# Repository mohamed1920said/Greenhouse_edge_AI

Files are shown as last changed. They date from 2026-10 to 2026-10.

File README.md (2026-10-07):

# Edge-AI Smart Greenhouse

This repository is an experimental greenhouse monitoring and control project built around an ESP32-class controller. It combines environmental sensors, relay-driven actuators, MQTT/Node-RED connectivity, over-the-air updates, persistent setpoints, and an Edge Impulse anomaly model. It also contains the project's firmware history and KiCad hardware designs.

The project is a prototype, not a finished safety controller. The firmware and PCB directories contain several generations with different assumptions. Start with `code section/final/final.ino` for the most integrated implementation, then verify it against the exact PCB and board you intend to use before compiling or wiring anything.

## System overview

```text
DHT22 + BH1750 + soil + flow + AC-voltage + DS1302
                         |
                         v
                    ESP32 tasks
              sensors / control / AI / MQTT
                 |                     |
                 v                     v
      heater, fan, pump,          MQTT broker
      humidifier, light           and Node-RED
```

The current `final.ino` uses FreeRTOS tasks to:

- sample temperature, humidity, light, soil moisture, water flow, AC voltage, and RTC time every two seconds;
- operate heater, fan, irrigation pump, humidifier, and grow light in automatic or manual mode;
- run an Edge Impulse anomaly classifier every five seconds and add rule-based fault diagnoses;
- publish state as JSON and accept JSON commands through MQTT every two seconds; and
- service Arduino OTA updates from the main loop.

Setpoints are stored in ESP32 Preferences/NVS and survive a restart.

## Repository map

| Path | Contents |
| --- | --- |
| `code section/final/final.ino` | Integrated firmware and the recommended starting point for review. |
| `code section/V0` through `V6`, and `V8` through `V11` | Historical firmware iterations. `V7` is not present; these are alternatives, not modules to compile together. |
| `code section/TEST PCB/CODE/CODE.ino` | PCB-oriented test firmware. |
| `code section/logger/` | Python serial logger and an example CSV log. |
| `code section/LIBRARY/GreenhouseDashboard .zip` | Archived dashboard-related project files. |
| `ia library/ei-mohamed_said-project-1-arduino-1.0.11.zip` | Exported Edge Impulse Arduino inference library used by `final.ino`. |
| `LIBRARY/` | Archived SimpleTimer and DHT library packages used during earlier iterations. |
| `NODE RED/flows.json` | Node-RED flow export. Review broker and topic settings before importing. |
| `PCB/central/` | KiCad central-board design and backups. |
| `PCB/central/external/` | KiCad external-board design, a nested `pfe` design, and backups. |
| `iot-dashboard`, `PCB/central/.history`, `PCB/central/external/.history` | Gitlink entries whose referenced repositories are not configured in this repository. |

Do not assume that a pin map or sensor type from an older `V*` directory matches `final.ino`; variants in this repository use different hardware and dependencies.

The three Gitlink entries above are stored like submodules, but there is no `.gitmodules` file with their source URLs. A normal clone therefore cannot retrieve their contents with `git submodule update`; the original repository locations would need to be identified and configured first.

## Current firmware pin map

The following table describes only `code section/final/final.ino`:

| Function | GPIO | Notes |
| --- | ---: | --- |
| BH1750 SDA / SCL | 8 / 9 | I2C address `0x23`. |
| DHT22 data | 4 | `DHTTYPE` is `DHT22`. |
| Soil-moisture analog input | 14 | Mapped from raw dry `3200` and wet `1100` to 0-100%; recalibrate for the actual probe. |
| Water-flow pulse input | 10 | Interrupt input with pull-up; conversion assumes 7.5 pulses per flow-rate unit. |
| Heater relay | 5 | Active low in the helper functions. |
| Fan relay | 6 | Active low. |
| Irrigation-pump relay | 7 | Active low. |
| Humidifier output | 15 | Active high, unlike the other actuator relays. |
| Light relay | 16 | Active low. |
| Red alarm LED | 42 | Driven high during configured lockout conditions. |
| AC-voltage analog input | 3 | Uses a firmware calibration factor of `237.0`; requires a safe isolated sensing circuit. |
| DS1302 CLK / DAT / RST | 11 / 12 / 13 | Three-wire RTC connection. |

These GPIO numbers are board-specific. Select an ESP32 variant that exposes them, check boot/strapping and ADC restrictions, and compare this table with the selected KiCad revision before connecting hardware.

## Firmware dependencies

Use an Arduino-compatible ESP32 development environment and install the libraries required by `final.ino`:

- DHT sensor library;
- BH1750;
- PubSubClient;
- ArduinoJson;
- a DS1302-compatible RTC library providing `ThreeWire.h` and `RtcDS1302.h`;
- the Edge Impulse Arduino library from `ia library/ei-mohamed_said-project-1-arduino-1.0.11.zip`; and
- the Wi-Fi, Preferences, ArduinoOTA, Wire, and FreeRTOS support supplied by the chosen ESP32 Arduino core.

Library and ESP32-core versions are not pinned. Record known-good versions after the first successful build.

## Configuration and first run

1. Review the schematic and choose the firmware/PCB revision that matches the assembled hardware.
2. Install the dependencies and import the Edge Impulse ZIP as an Arduino library.
3. In `final.ino`, replace `WIFI_SSID`, `WIFI_PASS`, `MQTT_SERVER`, and `MQTT_PORT` with values for the deployment network. Do not publish real credentials in source control.
4. Verify every GPIO, relay active level, soil calibration point, flow-sensor factor, and voltage-sensor calibration with actuators disconnected.
5. Start an MQTT broker reachable from the controller. The checked-in defaults point to `192.168.4.1:1883` without authentication or TLS.
6. Optionally import `NODE RED/flows.json`, then inspect all nodes and broker settings before deploying the flow. The exported flow targets HiveMQ Cloud over TLS on port 8883, while `final.ino` targets `192.168.4.1:1883` without TLS or authentication; the two configurations will not interoperate unchanged.
7. Build and upload `code section/final/final.ino`, open a serial monitor at `115200`, and validate sensor readings.
8. Test one low-voltage actuator channel at a time. Only connect pumps, heaters, or mains-powered equipment after the logic and fail-safe states have been independently verified.

`connectWiFi()` blocks until the configured network becomes available. A wrong SSID/password therefore prevents the remaining setup from completing.

## MQTT interface

The device uses these topics:

| Direction | Topic | Purpose |
| --- | --- | --- |
| Device to broker | `greenhouse/data` | Sensor values, actuator state, anomaly result, mode, setpoints, and manual commands. |
| Broker to device | `greenhouse/commands` | Mode, setpoint, and actuator-command changes. |

Example automatic-mode configuration:

```json
{
  "mode": "AUTO",
  "temp_low": 18,
  "temp_high": 26,
  "hum_low": 50,
  "lux_low": 50,
  "moist_low": 30
}
```

Example manual command:

```json
{
  "mode": "MANUAL",
  "heater": false,
  "fan": true,
  "pump": false,
  "humid": false,
  "light": true
}
```

Telemetry includes `temp`, `humid`, `lux`, `moist`, `water_flow`, `mains_voltage`, the five `*_state` fields, `anomaly_score`, `diagnosis`, `mode`, `hour`, the current setpoints, and the five `cmd_*` fields. Invalid DHT readings are published as JSON `null`.

## Automatic control and diagnostics

The checked-in defaults are 18-26 deg C, 50% minimum humidity, 50 lux minimum light, and 30% minimum soil moisture. In automatic mode:

- the heater runs below the low-temperature setpoint and the fan above the high-temperature setpoint;
- the humidifier runs below the humidity setpoint;
- the pump runs below the soil-moisture setpoint; and
- the light uses a 150-lux off hysteresis above its on threshold.

The AI input repeats temperature, humidity, soil moisture, light, and water-flow values across the model frame. Rule-based diagnoses take priority for invalid DHT data, pump-without-flow, flow-without-pump, low temperature while heating, and low humidity while humidifying. An anomaly score above `3.0` otherwise produces a warning.

The controller switches off selected loads and lights the red LED when measured AC voltage is between 10 V and 190 V, or when the diagnosis contains `CRITICAL`. This logic is an application safeguard, not certified electrical protection.

## Known limitations

- Wi-Fi credentials and broker details are hard-coded. MQTT has no authentication or TLS, and OTA has no configured password.
- The code reads the RTC hour but currently sets `isDaytime = true`; automatic lighting is therefore not actually limited to the stated day period.
- The AC-voltage calculation assumes a particular 240 V sensor calibration. It must not be connected directly to mains, and its values are not reliable on different hardware without calibration.
- Brownout lockout is applied only when the measured voltage is above 10 V and below 190 V. A disconnected or failed sensing circuit that reports 0 V bypasses this check rather than forcing a safe state.
- On a DHT failure, automatic temperature/humidity branches skip new commands, so prior fan or humidifier states can remain latched. The resulting `CRITICAL` path explicitly switches off only the heater and pump; it does not force every actuator off.
- Soil and flow conversions use fixed calibration constants. Edge Impulse results are meaningful only if sensor order, units, preprocessing, and library export match the model's training data.
- Relay polarity is mixed: the humidifier is active high while the other actuator helpers are active low.
- Historical firmware, archived libraries, Node-RED flow, and PCB backups can conflict with the final sketch. There is no single checked-in bill of materials or version manifest tying them together.
- Three Gitlink entries have no matching `.gitmodules` configuration, so the dashboard and history content they reference is not reproducible from this repository alone.
- Control and network loops have not been demonstrated here as fault tolerant. Network loss, MCU reset, stuck relays, sensor disconnection, dry running, and watchdog behavior require explicit tests.

## Safety

Heaters, pumps, humidifiers, grow lights, relays, water, and mains sensing create fire, shock, flooding, and equipment hazards. Use isolated and correctly rated power supplies, relay/driver modules, fuses, grounding, enclosures, strain relief, emergency shutoff, and independent temperature/water-level protection. Keep low-voltage electronics separated from mains and wet areas. Test with safe dummy loads first, and do not operate this prototype unattended or use it as the only protection for plants, property, or people.

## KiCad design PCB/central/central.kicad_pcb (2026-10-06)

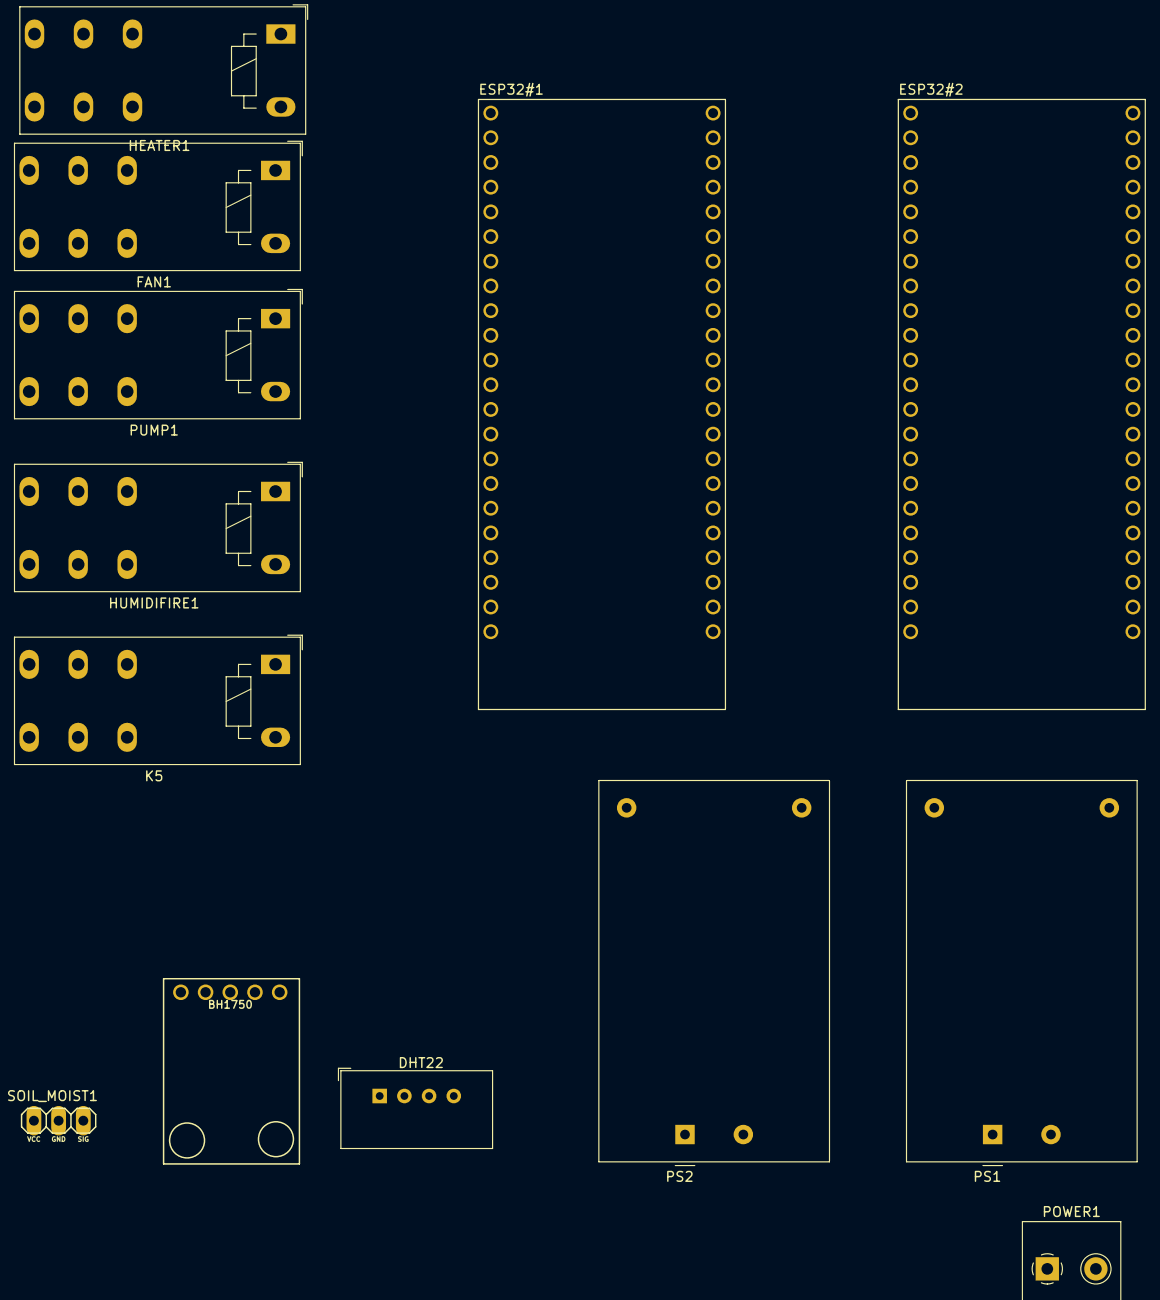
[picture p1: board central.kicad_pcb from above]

Board: 2 copper layers, 13 parts (0 on the bottom side), 14 nets, no tracks yet.

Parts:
BH1750: ZC362800_
DHT22: AM2302; ASAIR_AM2302_P2.54mm_Vertical
ESP32#1, ESP32#2: ESP32-S3-DEVKITC-1U-N8R8; MODULE_ESP32-S3-DEVKITC-1U-N8R8
FAN1: RT314A05; Relay_SPDT_Schrack-RT1-16A-FormC_RM5mm
HEATER1: RT314A05; Relay_SPDT_Schrack-RT1-16A-FormC_RM5mm
HUMIDIFIRE1: RT314A05; Relay_SPDT_Schrack-RT1-16A-FormC_RM5mm
K5: GROW_LIGHT; Relay_SPDT_Schrack-RT1-16A-FormC_RM5mm
POWER1: Screw_Terminal_01x02; TerminalBlock_Philmore_TB132_1x02_P5.00mm_Horizontal
PS1: HLK-5M05; Converter_ACDC_HiLink_HLK-5Mxx
PS2: HLK-5M12; Converter_ACDC_HiLink_HLK-5Mxx
PUMP1: RT314A05; Relay_SPDT_Schrack-RT1-16A-FormC_RM5mm
SOIL_MOIST1: SEN-13322

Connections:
3V3: ESP32#1.J1_1 (3V3), ESP32#1.J1_2 (3V3), ESP32#2.J1_1 (3V3), ESP32#2.J1_2 (3V3)
5V: BH1750.VCC, DHT22.1 (VDD), ESP32#2.J1_21 (5V0), HUMIDIFIRE1.11, K5.11, PS1.4 (+Vout), SOIL_MOIST1.1 (VCC)
12V: FAN1.11, HEATER1.11, PS2.4 (+Vout), PUMP1.11
GND: BH1750.GND, DHT22.3 (GND), DHT22.4 (GND), ESP32#1.J1_22 (GND), ESP32#1.J3_1 (GND), ESP32#1.J3_21 (GND), ESP32#1.J3_22 (GND), ESP32#2.J1_22 (GND), ESP32#2.J3_1 (GND), ESP32#2.J3_21 (GND), ESP32#2.J3_22 (GND), FAN1.A1, HEATER1.A1, HUMIDIFIRE1.A1, K5.A1, PS1.3 (-Vout), PS2.3 (-Vout), PUMP1.A1, SOIL_MOIST1.2 (GND)
unnamed: POWER1.1, PS1.1 (AC/L), PS2.1 (AC/L)
unnamed: POWER1.2, PS1.2 (AC/N), PS2.2 (AC/N)
PIN_5: ESP32#1.J1_5 (GPIO5), HEATER1.A2
PIN_6: ESP32#1.J1_6 (GPIO6), FAN1.A2
PIN_7: ESP32#1.J1_7 (GPIO7), PUMP1.A2
PIN_8: BH1750.SDA, ESP32#1.J1_12 (GPIO8)
PIN_9: BH1750.SCL, ESP32#1.J1_15 (GPIO9)
PIN_14: ESP32#1.J1_20 (GPIO14), SOIL_MOIST1.3 (SIG)
PIN_15: ESP32#1.J1_8 (GPIO15), HUMIDIFIRE1.A2
PIN_16: ESP32#1.J1_9 (GPIO16), K5.A2

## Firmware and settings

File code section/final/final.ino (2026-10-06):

#include <DHT.h>
#include <Wire.h>
#include <BH1750.h>
#include <WiFi.h>
#include <WiFiClient.h>
#include <PubSubClient.h>
#include <ArduinoJson.h>
#include <Preferences.h>
#include <ArduinoOTA.h>

// --- NEW RTC LIBRARIES (DS1302) ---
#include <ThreeWire.h>  
#include <RtcDS1302.h>


#include <mohamed_said-project-1_inferencing.h>

// =============================================================
// WIFI + MQTT (LOCAL BROKER)
// =============================================================
const char* WIFI_SSID   = "GreenhouseNet";
const char* WIFI_PASS   = "12345678";
const char* MQTT_SERVER = "192.168.4.1";
const int   MQTT_PORT   = 1883;

const char* TOPIC_DATA  = "greenhouse/data";
const char* TOPIC_CMD   = "greenhouse/commands";

// =============================================================
// PINS
// =============================================================
#define PIN_SDA      8   // I2C for BH1750
#define PIN_SCL      9   // I2C for BH1750
#define PIN_DHT      4
#define PIN_SOIL     14
#define PIN_WATER    10
#define PIN_HEATER   5
#define PIN_FAN      6
#define PIN_PUMP     7
#define PIN_HUMID    15
#define PIN_LIGHT    16
#define PIN_LED_RED  42
#define PIN_VOLTAGE  3   

// DS1302 RTC Pins
#define PIN_RTC_CLK  11
#define PIN_RTC_DAT  12
#define PIN_RTC_RST  13

// =============================================================
// DRIVERS & GLOBALS
// =============================================================
#define DHTTYPE DHT22
DHT dht(PIN_DHT, DHTTYPE);
BH1750 lightMeter;
WiFiClient espClient;
PubSubClient client(espClient);
Preferences preferences;

// Initialize DS1302
ThreeWire myWire(PIN_RTC_DAT, PIN_RTC_CLK, PIN_RTC_RST); // DAT, CLK, RST
RtcDS1302<ThreeWire> rtc(myWire);

// =============================================================
// SETTINGS
// =============================================================
const float ANOMALY_THRESHOLD = 3.0f; 

volatile bool manualMode = false;

// Setpoints (Overwritten by Flash Memory)
float sp_temp_low  = 18.0f;
float sp_temp_high = 26.0f;
float sp_hum_low   = 50.0f;
float sp_lux_low   = 50.0f;
float sp_moist_low = 30.0f;

volatile int cmd_heater = 0;
volatile int cmd_fan    = 0;
volatile int cmd_pump   = 0;
volatile int cmd_humid  = 0;
volatile int cmd_light  = 0;

// =============================================================
// SHARED STATE
// =============================================================
struct SharedData {
  float temp, humid, lux, moist, water_flow, mains_voltage;
  int heater_state, fan_state, pump_state, light_state, humid_state;
  float anomaly_score;
  String diagnosis;
  int current_hour;
};

SharedData systemState = {
  0.0f, 0.0f, 0.0f, 0.0f, 0.0f, 0.0f,
  0, 0, 0, 0, 0,
  0.0f, "Booting...", 12
};

SemaphoreHandle_t xMutex = NULL;
float features[EI_CLASSIFIER_DSP_INPUT_FRAME_SIZE];

// =============================================================
// HELPERS
// =============================================================
void relayWrite(int pin, bool turnOn) {
  if (pin == PIN_HUMID) digitalWrite(pin, turnOn ? HIGH : LOW);
  else digitalWrite(pin, turnOn ? LOW : HIGH);
}

int relayRead(int pin) {
  if (pin == PIN_HUMID) return (digitalRead(pin) == HIGH) ? 1 : 0;
  else return (digitalRead(pin) == LOW) ? 1 : 0;
}

float readSoilMoisture() {
  const int raw_dry = 3200, raw_wet = 1100;
  int raw = analogRead(PIN_SOIL);
  float pct = (float)(raw_dry - raw) / (float)(raw_dry - raw_wet) * 100.0f;
  if (pct < 0.0f) pct = 0.0f;
  if (pct > 100.0f) pct = 100.0f;
  return pct;
}

volatile uint32_t flowPulseCount = 0;
void IRAM_ATTR flowPulseISR() { flowPulseCount++; }
float calculateFlowRate(uint32_t elapsedMs) {
  uint32_t pulses = flowPulseCount; flowPulseCount = 0;
  if (elapsedMs == 0) return 0.0f;
  return ((pulses * 1000.0f) / elapsedMs) / 7.5f; 
}

float readACVoltage() {
  uint32_t start_time = millis();
  int max_val = 0, min_val = 4095;
  while((millis() - start_time) < 40) { // 40ms = 2 full AC cycles
    int val = analogRead(PIN_VOLTAGE);
    if(val > max_val) max_val = val;
    if(val < min_val) min_val = val;
  }
  float v_pp = ((max_val - min_val) * 3.3f) / 4095.0f;
  float v_rms = v_pp / 2.828f;
  float CALIBRATION_FACTOR = 237.0f; // Calibrated for 240V
  float actual_voltage = v_rms * CALIBRATION_FACTOR;
  if (actual_voltage < 10.0f) actual_voltage = 0.0f; 
  return actual_voltage;
}

// =============================================================
// MQTT & WIFI
// =============================================================
void connectWiFi() {
  WiFi.mode(WIFI_STA); WiFi.begin(WIFI_SSID, WIFI_PASS);
  while (WiFi.status() != WL_CONNECTED) delay(500);
}

void reconnectMQTT() {
  if (WiFi.status() == WL_CONNECTED && client.connect("ESP32_GH")) {
    client.subscribe(TOPIC_CMD);
  }
}

void onMqttMessage(char* topic, byte* payload, unsigned int length) {
  StaticJsonDocument<512> doc;
  if (deserializeJson(doc, payload, length)) return;

  if (xSemaphoreTake(xMutex, pdMS_TO_TICKS(100)) == pdTRUE) {
    if (doc.containsKey("mode")) manualMode = (doc["mode"].as<String>() == "MANUAL");

    bool configChanged = false;
    if (doc.containsKey("temp_low"))  { sp_temp_low  = doc["temp_low"]; configChanged = true; }
    if (doc.containsKey("temp_high")) { sp_temp_high = doc["temp_high"]; configChanged = true; }
    if (doc.containsKey("hum_low"))   { sp_hum_low   = doc["hum_low"]; configChanged = true; }
    if (doc.containsKey("lux_low"))   { sp_lux_low   = doc["lux_low"]; configChanged = true; }
    if (doc.containsKey("moist_low")) { sp_moist_low = doc["moist_low"]; configChanged = true; }
    if (sp_temp_high < sp_temp_low) { float t = sp_temp_low; sp_temp_low = sp_temp_high; sp_temp_high = t; }

    if (configChanged) {
      preferences.putFloat("sp_t_l", sp_temp_low); preferences.putFloat("sp_t_h", sp_temp_high);
      preferences.putFloat("sp_h_l", sp_hum_low); preferences.putFloat("sp_l_l", sp_lux_low);
      preferences.putFloat("sp_m_l", sp_moist_low);
    }

    if (doc.containsKey("heater")) cmd_heater = doc["heater"] ? 1 : 0;
    if (doc.containsKey("fan"))    cmd_fan    = doc["fan"] ? 1 : 0;
    if (doc.containsKey("pump"))   cmd_pump   = doc["pump"] ? 1 : 0;
    if (doc.containsKey("humid"))  cmd_humid  = doc["humid"] ? 1 : 0;
    if (doc.containsKey("light"))  cmd_light  = doc["light"] ? 1 : 0;

    xSemaphoreGive(xMutex);
  }
}

// =============================================================
// TASKS
// =============================================================
void TaskSensors(void* pvParameters) {
  uint32_t lastFlowCheck = millis();
  for (;;) {
    float t = dht.readTemperature(); float h = dht.readHumidity();
    float l = lightMeter.readLightLevel(); float m = readSoilMoisture();
    uint32_t now = millis(); float w = calculateFlowRate(now - lastFlowCheck); lastFlowCheck = now;
    float v_ac = readACVoltage();
    
    // Get Time from DS1302
    RtcDateTime now_time = rtc.GetDateTime();

    if (isnan(t) || t < -40 || t > 80) t = -999.0f;
    if (isnan(h) || h < 0 || h > 100) h = -999.0f;
    if (l < 0) l = 0;

    if (xSemaphoreTake(xMutex, portMAX_DELAY) == pdTRUE) {
      systemState.temp = t; systemState.humid = h; systemState.lux = l;
      systemState.moist = m; systemState.water_flow = w; systemState.mains_voltage = v_ac;
      systemState.heater_state = relayRead(PIN_HEATER); systemState.fan_state = relayRead(PIN_FAN);
      systemState.pump_state = relayRead(PIN_PUMP); systemState.light_state = relayRead(PIN_LIGHT);
      systemState.humid_state = relayRead(PIN_HUMID); systemState.current_hour = now_time.Hour(); 
      xSemaphoreGive(xMutex);
    }
    vTaskDelay(2000 / portTICK_PERIOD_MS);
  }
}

void TaskAI(void* pvParameters) {
  for (;;) {
    float t, h, l, m, w; int pump_state, heater_state, humid_state, light_state;
    if (xSemaphoreTake(xMutex, portMAX_DELAY) == pdTRUE) {
      t = systemState.temp; h = systemState.humid; l = systemState.lux; m = systemState.moist; w = systemState.water_flow;
      pump_state = systemState.pump_state; heater_state = systemState.heater_state; 
      humid_state = systemState.humid_state; light_state = systemState.light_state;
      xSemaphoreGive(xMutex);
    }

    for (size_t i = 0; i < EI_CLASSIFIER_DSP_INPUT_FRAME_SIZE; i += 5) {
      features[i] = t; if (i+1 < EI_CLASSIFIER_DSP_INPUT_FRAME_SIZE) features[i+1] = h;
      if (i+2 < EI_CLASSIFIER_DSP_INPUT_FRAME_SIZE) features[i+2] = m;
      if (i+3 < EI_CLASSIFIER_DSP_INPUT_FRAME_SIZE) features[i+3] = l;
      if (i+4 < EI_CLASSIFIER_DSP_INPUT_FRAME_SIZE) features[i+4] = w;
    }

    signal_t signal; numpy::signal_from_buffer(features, EI_CLASSIFIER_DSP_INPUT_FRAME_SIZE, &signal);
    ei_impulse_result_t result = { 0 }; run_classifier(&signal, &result, false);

    float score = result.anomaly; String diag = "Normal";

    if (t == -999.0f) diag = "CRITICAL: Temperature sensor failure";
    else if (h == -999.0f) diag = "CRITICAL: Humidity sensor failure";
    else if (pump_state == 1 && w < 0.1f) diag = "CRITICAL: Pipe blocked (pump ON, no flow)";
    else if (pump_state == 0 && w > 0.1f) diag = "CRITICAL: Water leak detected";
    else if (heater_state == 1 && t < 15.0f) diag = "CRITICAL: Heater failure";
    else if (humid_state == 1 && h < 40.0f) diag = "CRITICAL: Humidifier failure";
    else if (score > ANOMALY_THRESHOLD) diag = "WARNING: AI detected abnormal environment";

    if (xSemaphoreTake(xMutex, portMAX_DELAY) == pdTRUE) {
      systemState.anomaly_score = score; systemState.diagnosis = diag;
      xSemaphoreGive(xMutex);
    }
    vTaskDelay(5000 / portTICK_PERIOD_MS);
  }
}

void TaskControl(void* pvParameters) {
  for (;;) {
    float t, h, l, m, v_ac; String diag; bool modeManual; int hr;
    float tLow, tHigh, hLow, luxLow, moistLow; int cHeater, cFan, cPump, cHumid, cLight;

    if (xSemaphoreTake(xMutex, portMAX_DELAY) == pdTRUE) {
      t = systemState.temp; h = systemState.humid; l = systemState.lux; m = systemState.moist; 
      v_ac = systemState.mains_voltage; diag = systemState.diagnosis; hr = systemState.current_hour;
      modeManual = manualMode; tLow = sp_temp_low; tHigh = sp_temp_high; hLow = sp_hum_low; 
      luxLow = sp_lux_low; moistLow = sp_moist_low;
      cHeater = cmd_heater; cFan = cmd_fan; cPump = cmd_pump; cHumid = cmd_humid; cLight = cmd_light;
      xSemaphoreGive(xMutex);
    }

    bool safety_lockout = false;
    
    // BROWNOUT PROTECTION
    if (v_ac > 10.0f && v_ac < 190.0f) { 
      relayWrite(PIN_HEATER, false); relayWrite(PIN_PUMP, false); relayWrite(PIN_FAN, false);
      digitalWrite(PIN_LED_RED, HIGH); safety_lockout = true; 
    } 
    else if (diag.indexOf("CRITICAL") != -1) {
      relayWrite(PIN_HEATER, false); relayWrite(PIN_PUMP, false); 
      digitalWrite(PIN_LED_RED, HIGH); safety_lockout = true;
    } else {
      digitalWrite(PIN_LED_RED, LOW);
    }

    if (!safety_lockout) {
      if (modeManual) {
        relayWrite(PIN_HEATER, cHeater); relayWrite(PIN_FAN, cFan); relayWrite(PIN_PUMP, cPump);
        relayWrite(PIN_HUMID, cHumid); relayWrite(PIN_LIGHT, cLight);
      } else {
        
        // 1. THERMAL & MOISTURE
        if (t != -999.0f) {
          if (t < tLow) { relayWrite(PIN_HEATER, true); relayWrite(PIN_FAN, false); }
          else if (t > tHigh) { relayWrite(PIN_HEATER, false); relayWrite(PIN_FAN, true); }
          else { relayWrite(PIN_HEATER, false); relayWrite(PIN_FAN, false); }
        }
        if (h != -999.0f) relayWrite(PIN_HUMID, (h < hLow));
        relayWrite(PIN_PUMP,  (m < moistLow));
        
        bool isDaytime = true ; // 6 AM to 8 PM
        bool current_light = (relayRead(PIN_LIGHT) == 1);
        
        if (isDaytime) {
          if (!current_light && (l < luxLow)) {
            relayWrite(PIN_LIGHT, true);
          } 
          else if (current_light && (l > (luxLow + 150.0f))) {
            relayWrite(PIN_LIGHT, false);
          }
        } else {
          // It is Nighttime -> Force light OFF
          relayWrite(PIN_LIGHT, false);
        }
      }
    }
    vTaskDelay(2000 / portTICK_PERIOD_MS);
  }
}

void TaskMQTT(void* pvParameters) {
  for (;;) {
    if (WiFi.status() != WL_CONNECTED) connectWiFi();
    if (!client.connected()) reconnectMQTT();
    client.loop();

    StaticJsonDocument<768> doc;
    if (xSemaphoreTake(xMutex, portMAX_DELAY) == pdTRUE) {
      
      if (systemState.temp == -999.0f) doc["temp"] = nullptr;
      else doc["temp"] = systemState.temp;

      if (systemState.humid == -999.0f) doc["humid"] = nullptr;
      else doc["humid"] = systemState.humid;

      doc["lux"] = systemState.lux; doc["moist"] = systemState.moist; 
      doc["water_flow"] = systemState.water_flow; doc["mains_voltage"] = systemState.mains_voltage;
      
      doc["heater_state"] = relayRead(PIN_HEATER); doc["fan_state"] = relayRead(PIN_FAN);
      doc["pump_state"] = relayRead(PIN_PUMP); doc["light_state"] = relayRead(PIN_LIGHT);
      doc["humid_state"] = relayRead(PIN_HUMID);
      
      doc["anomaly_score"] = systemState.anomaly_score; doc["diagnosis"] = systemState.diagnosis;
      doc["mode"] = manualMode ? "MANUAL" : "AUTO";
      doc["hour"] = systemState.current_hour; 
      
      doc["temp_low"] = sp_temp_low; doc["temp_high"] = sp_temp_high; doc["hum_low"] = sp_hum_low;
      doc["lux_low"] = sp_lux_low; doc["moist_low"] = sp_moist_low;

      doc["cmd_heater"] = cmd_heater; doc["cmd_fan"] = cmd_fan; doc["cmd_pump"] = cmd_pump;
      doc["cmd_humid"] = cmd_humid; doc["cmd_light"] = cmd_light;
      xSemaphoreGive(xMutex);
    }

    char buffer[1024]; size_t n = serializeJson(doc, buffer, sizeof(buffer));
    if (n > 0) client.publish(TOPIC_DATA, buffer);
    vTaskDelay(2000 / portTICK_PERIOD_MS);
  }
}

// =============================================================
// SETUP & LOOP
// =============================================================
void setup() {
  Serial.begin(115200);
  preferences.begin("ghouse", false);
  sp_temp_low  = preferences.getFloat("sp_t_l", 18.0f);
  sp_temp_high = preferences.getFloat("sp_t_h", 26.0f);
  sp_hum_low   = preferences.getFloat("sp_h_l", 50.0f);
  sp_lux_low   = preferences.getFloat("sp_l_l", 50.0f);
  sp_moist_low = preferences.getFloat("sp_m_l", 30.0f);

  // Init Sensors
  Wire.begin(PIN_SDA, PIN_SCL);
  dht.begin();
  
  // Init DS1302
  rtc.Begin();
  RtcDateTime compiled = RtcDateTime(__DATE__, __TIME__);
  if (!rtc.IsDateTimeValid()) rtc.SetDateTime(compiled);
  if (!rtc.GetIsRunning()) rtc.SetIsRunning(true);
  
  Wire.beginTransmission(0x23);
  if (Wire.endTransmission() == 0) lightMeter.begin(BH1750::CONTINUOUS_HIGH_RES_MODE, 0x23, &Wire);

  // Init Pins
  pinMode(PIN_HEATER, OUTPUT); pinMode(PIN_FAN, OUTPUT); pinMode(PIN_PUMP, OUTPUT);
  pinMode(PIN_HUMID, OUTPUT); pinMode(PIN_LIGHT, OUTPUT); pinMode(PIN_LED_RED, OUTPUT);
  pinMode(PIN_WATER, INPUT_PULLUP);
  relayWrite(PIN_HEATER, false); relayWrite(PIN_FAN, false); relayWrite(PIN_PUMP, false);
  relayWrite(PIN_HUMID, false); relayWrite(PIN_LIGHT, false); digitalWrite(PIN_LED_RED, LOW);

  attachInterrupt(digitalPinToInterrupt(PIN_WATER), flowPulseISR, RISING);

  xMutex = xSemaphoreCreateMutex();
  connectWiFi();
  
  ArduinoOTA.setHostname("Smart-Greenhouse"); ArduinoOTA.begin();
  client.setServer(MQTT_SERVER, MQTT_PORT); client.setCallback(onMqttMessage);
  client.setBufferSize(1024); client.setKeepAlive(20); client.setSocketTimeout(3);

  // Start FreeRTOS Tasks
  xTaskCreatePinnedToCore(TaskSensors, "Sensors", 4096, NULL, 2, NULL, 1);
  xTaskCreatePinnedToCore(TaskControl, "Control", 6144, NULL, 1, NULL, 1);
  xTaskCreatePinnedToCore(TaskMQTT,    "MQTT",    6144, NULL, 1, NULL, 1);
  xTaskCreatePinnedToCore(TaskAI,      "AI",      8192, NULL, 1, NULL, 0);
}

void loop() {
  ArduinoOTA.handle();
  vTaskDelay(10 / portTICK_PERIOD_MS);
}

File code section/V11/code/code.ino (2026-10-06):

#include <DHT.h>
#include <Wire.h>
#include <BH1750.h>
#include <WiFi.h>
#include <WiFiClient.h>
#include <PubSubClient.h>
#include <ArduinoJson.h>
#include <SPI.h>
#include <SD.h>

// DS1302 (3-wire RTC: CLK/DATA/RST)
#include <ThreeWire.h>
#include <RtcDS1302.h>

#include <mohamed_said-project-1_inferencing.h>

// =============================================================
// WIFI + MQTT (LOCAL BROKER)
// =============================================================
const char* WIFI_SSID   = "GreenhouseNet";
const char* WIFI_PASS   = "12345678";
const char* MQTT_SERVER = "192.168.4.1";
const int   MQTT_PORT   = 1883;

const char* TOPIC_DATA  = "greenhouse/data";
const char* TOPIC_CMD   = "greenhouse/commands";

// =============================================================
// PINS (YOUR EXISTING PINS)
// =============================================================
#define PIN_SDA      8
#define PIN_SCL      9
#define PIN_DHT      4
#define PIN_SOIL     14
#define PIN_WATER    10
#define PIN_HEATER   5
#define PIN_FAN      6
#define PIN_PUMP     7
#define PIN_HUMID    16
#define PIN_LIGHT    15
#define PIN_LED_RED  42

// =============================================================
// ADD THESE PINS (YOU MUST SET THEM TO MATCH YOUR WIRING)
// =============================================================
// ---- RTC DS1302 pins (module: VCC GND CLK DATA RST) ----
#define PIN_RTC_CLK  1   // TODO: set to your RTC CLK GPIO
#define PIN_RTC_DAT  2   // TODO: set to your RTC DATA GPIO
#define PIN_RTC_RST  3   // TODO: set to your RTC RST/CE GPIO

// ---- SD card SPI pins (module: CS SCK MISO MOSI) ----
// IMPORTANT: do NOT conflict with PIN_WATER=10, and avoid your relay pins too.
#define PIN_SD_CS    41  // TODO: set to your SD CS GPIO
#define PIN_SD_SCK   40  // TODO: set to your SD SCK GPIO
#define PIN_SD_MISO  39  // TODO: set to your SD MISO GPIO
#define PIN_SD_MOSI  38  // TODO: set to your SD MOSI GPIO

// =============================================================
// DRIVERS
// =============================================================
#define DHTTYPE DHT11
DHT dht(PIN_DHT, DHTTYPE);
BH1750 lightMeter;
WiFiClient espClient;
PubSubClient client(espClient);

// RTC objects
ThreeWire rtcWire(PIN_RTC_DAT, PIN_RTC_CLK, PIN_RTC_RST); // DAT, CLK, RST
RtcDS1302<ThreeWire> Rtc(rtcWire);
bool rtcOK = false;

// SD objects
SPIClass sdSPI(FSPI);
bool sdOK = false;

// =============================================================
// SETTINGS
// =============================================================
const float ANOMALY_THRESHOLD = 1.0f;

// Mode: false=AUTO, true=MANUAL
volatile bool manualMode = false;

// Setpoints
float sp_temp_low  = 18.0f;
float sp_temp_high = 26.0f;
float sp_hum_low   = 50.0f;
float sp_lux_low   = 200.0f;
float sp_moist_low = 30.0f;

// Manual desired actuator commands (single source of truth)
volatile int cmd_heater = 0;
volatile int cmd_fan    = 0;
volatile int cmd_pump   = 0;
volatile int cmd_humid  = 0;
volatile int cmd_light  = 0;

// =============================================================
// WATER FLOW
// =============================================================
volatile uint32_t flowPulseCount = 0;
void IRAM_ATTR flowPulseISR() { flowPulseCount++; }

float calculateFlowRate(uint32_t elapsedMs) {
  uint32_t pulses = flowPulseCount;
  flowPulseCount = 0;
  if (elapsedMs == 0) return 0.0f;
  float freq = (pulses * 1000.0f) / elapsedMs; // pulses/sec
  return freq / 7.5f; // L/min
}

// =============================================================
// SHARED STATE
// =============================================================
struct SharedData {
  float temp, humid, lux, moist, water_flow;
  int heater_state, fan_state, pump_state, light_state, humid_state;
  float anomaly_score;
  String diagnosis;
};

SharedData systemState = {
  0.0f, 0.0f, 0.0f, 0.0f, 0.0f,
  0, 0, 0, 0, 0,
  0.0f, "Booting..."
};

SemaphoreHandle_t xMutex = NULL;
float features[EI_CLASSIFIER_DSP_INPUT_FRAME_SIZE];

// =============================================================
// HELPERS
// =============================================================
void relayWrite(int pin, bool turnOn) {
  // Active-low relay: ON->LOW, OFF->HIGH
  digitalWrite(pin, turnOn ? LOW : HIGH);
}

int relayRead(int pin) {
  return (digitalRead(pin) == LOW) ? 1 : 0;
}

float readSoilMoisture() {
  const int raw_dry = 3200;
  const int raw_wet = 1100;
  int raw = analogRead(PIN_SOIL);
  float pct = (float)(raw_dry - raw) / (float)(raw_dry - raw_wet) * 100.0f;
  if (pct < 0.0f) pct = 0.0f;
  if (pct > 100.0f) pct = 100.0f;
  return pct;
}

// ---------- RTC timestamp ----------
String isoTimestampNow() {
  if (!rtcOK) return String("1970-01-01T00:00:00");
  RtcDateTime dt = Rtc.GetDateTime();
  if (!Rtc.IsDateTimeValid()) return String("1970-01-01T00:00:00");

  char buf[25];
  snprintf(buf, sizeof(buf), "%04u-%02u-%02uT%02u:%02u:%02u",
           dt.Year(), dt.Month(), dt.Day(),
           dt.Hour(), dt.Minute(), dt.Second());
  return String(buf);
}

// ---------- SD log ----------
void sdWriteHeaderIfNeeded() {
  if (!sdOK) return;
  if (!SD.exists("/greenhouse_log.csv")) {
    File f = SD.open("/greenhouse_log.csv", FILE_WRITE);
    if (f) {
      f.println("ts,mode,temp,humid,lux,moist,water_flow,heater_state,fan_state,pump_state,humid_state,light_state,anomaly_score,diagnosis");
      f.close();
    }
  }
}

void appendLogLine(const String& line) {
  if (!sdOK) return;
  File f = SD.open("/greenhouse_log.csv", FILE_APPEND);
  if (!f) {
    Serial.println("SD open append failed");
    return;
  }
  f.println(line);
  f.close();
}

// =============================================================
// WIFI
// =============================================================
void connectWiFi() {
  Serial.println("Connecting WiFi...");
  WiFi.disconnect(true, true);
  delay(300);

  WiFi.mode(WIFI_STA);
  WiFi.setSleep(false);
  WiFi.setAutoReconnect(true);
  WiFi.persistent(false);
  WiFi.begin(WIFI_SSID, WIFI_PASS);

  int tries = 0;
  while (WiFi.status() != WL_CONNECTED && tries < 50) {
    delay(300);
    Serial.print(".");
    tries++;
  }
  Serial.println();

  if (WiFi.status() == WL_CONNECTED) {
    Serial.println("WiFi connected");
    Serial.print("SSID    : "); Serial.println(WiFi.SSID());
    Serial.print("Local IP: "); Serial.println(WiFi.localIP());
    Serial.print("Gateway : "); Serial.println(WiFi.gatewayIP());
    Serial.print("RSSI    : "); Serial.println(WiFi.RSSI());
  } else {
    Serial.println("WiFi failed -> restart");
    ESP.restart();
  }
}
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
